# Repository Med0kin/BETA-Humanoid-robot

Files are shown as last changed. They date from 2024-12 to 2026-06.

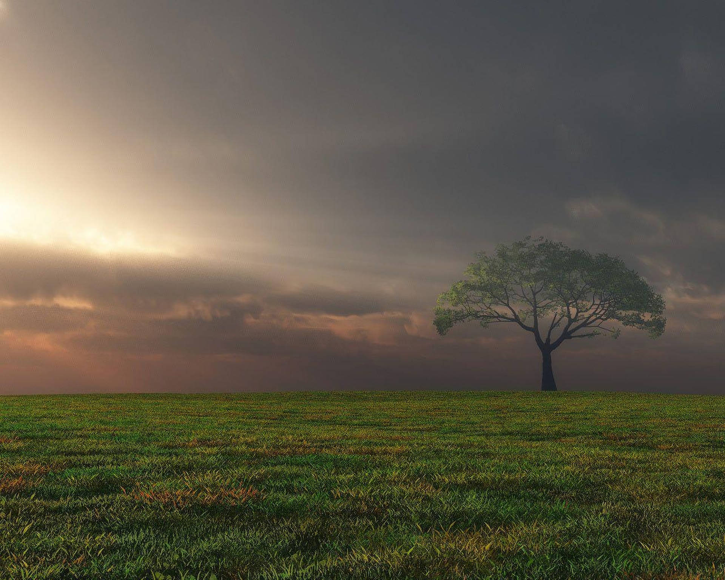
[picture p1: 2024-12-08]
gui/view/resources/background.png

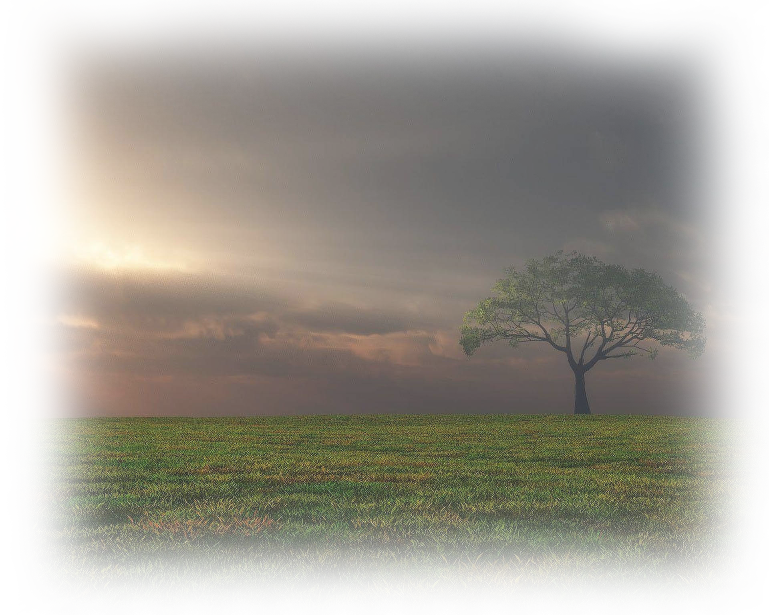
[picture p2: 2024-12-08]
gui/view/resources/background_01.png

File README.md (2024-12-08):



## Table of content

- [Humanoid robot *BETA*](#humanoid-robot-beta)
- [Built with](#built-with)
  - [Hardware components](#hardware-components)
  - [Programming language](#programming-language)
  - [Used libraries](#used-libraries)
- [Construction](#construction)
- [Power supply](#power-supply)
- [Servo control](#servo-control)
  - [Disclaimer](#disclaimer)
  - [Pulse Servo](#pulse-servo)
  - [Bus Servo](#bus-servo)
  - [Sequencial movement](#sequencial-movement)
- [Application](#application)
- [Speech-to-text](#speech-to-text)
- [Pose estimation](#pose-estimation)
- [Safety precautions](#safety-precautions)
- [Future plans](#future-plans)

## Humanoid robot *BETA*

BETA is an ambitious undertaking that seeks to develop a humanoid robot possessing a range of human-like capabilities, including the ability to walk, see, and communicate verbally.

Conceived in 2018, the project has undergone several transformations and upgrades over the years. Currently, it is being developed as part of the *"Koło Naukowe Humanoid"* student research circle. Updates on its progress and new features are regularly shared on the group's [Facebook page](https://www.facebook.com/KNHStyleOfficial).

<p align="center">
  
</p>

## Built with

### Hardware components

- [Raspberry Pi 4 Model B](https://www.raspberrypi.com/products/raspberry-pi-4-model-b/)
- [Raspberry Pi display](https://www.dfrobot.com/product-1784.html)
- [Bus servos](https://en.ocservo.com/?post_type=products&page_id=16170)
- Pulse servos: [RDS3235-180](https://pl.aliexpress.com/item/32734965011.html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) and [RDS3115-270](https://pl.aliexpress.com/item/32270225462.html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)
- USB Webcam

### Programming language

The programming language of choice for the project is Python. This decision was made because of its ease of use, large community, large number of libraries and frameworks and cross-platform compatilibity. Additionally, Python is a versatile language that can be used to develop a wide range of applications, including those that are used for the control of the robot's servos, the implementation of its vision system, and the development of its speech recognition capabilities.

### Used libraries

- [PySide2](https://pypi.org/project/PySide2/) - GUI toolkit used in [Application](#application)
- [Selenium](https://www.selenium.dev/) - automation of browser used in [Speech-to-text](#speech-to-text)
- [OpenCV](https://opencv.org/) - real-time computer vision used in [Pose estimation](#pose-estimation)
- [OCServo](https://github.com/Shinnken/OCServo_App/) - servo control app used in [Servo control](#servo-control)
- [pigpio](https://pypi.org/project/pigpio/) - control of GPIO to generate software PWM signal to control [Pulse servos](#disclaimer).

## Construction

The framework of the robot is composed of a hybrid of components that are either 3D-printed, purchased, or self-fabricated. The design of these parts was created in Blender, a 3D modeling software, and subsequently constructed by our team.

<p align="center">
  
</p>

Additionally, a 3D printer was utilized to produce the robot's chest component.

## Power supply

Humanoid robot BETA is powered by a combination of two step-up voltage regulators that convert 5V to 6V and 5V to 12V respectively. While this power supply configuration is functional, it is not an ideal solution for providing power to the robot's components.

## Servo control

As previously stated, our project utilizes two distinct types of servos. Due to their differing control mechanisms, we have partitioned their descriptions into two distinct subcategories.

### Disclaimer

Our use of the term "pulse" refers to a conventional servo that employs a Pulse Width Modulation (PWM) signal as its control input.

### Pulse Servo

Using mentioned library we've created tool to control servos with single commands.
To affix the servos to the robot's framework, we employ brackets that are included in the kit alongside the servos. The Raspberry Pi's GPIO pins serve as the source of the PWM signal, which is generated by utilizing the software [pigpio library](https://pypi.org/project/pigpio/). We have developed a tool utilizing the aforementioned library, which allows for the control of the servos through the use of single commands.

<p align="center">
  
</p>

During the process of developing the robot, it became apparent that the existing servos were not ideally suited to our requirements, as they were prone to excessive play and struggled to maintain a fixed position. As a result, we made the decision to incorporate [Bus servos](#bus-servo) in the leg joints, as these offer superior stability and control. By leveraging this approach, we can enhance the overall performance and reliability of the system, while enabling greater precision and accuracy in its movements.

### Bus Servo

In regards to the management of the second group of servos, communication is established through the utilization of the UART protocol, as the servos in question incorporate internal electronics. This approach enables efficient transmission of commands and data, as well as simplifying the wiring and control of the servos. By interfacing with the internal electronics of the servos, the system can achieve greater precision and flexibility in its movements.

<p align="center">
  
</p>

For more information about Bus servo control check out our [Servo library](https://github.com/Shinnken/OCServo_App/).

### Sequencial movement

To achieve smooth movement of our robot, we have developed a tool that enables the sequential control of servos. The primary objective of this tool is to facilitate the coordinated movement of servos to achieve seamless motion.

The program operates by utilizing text files, which contain data regarding the angles of each servo required for a given pose. By compiling a list of various poses, complex movements can be achieved through the sequential execution of poses. To create these text files, we have developed a custom tool that allows for the adjustment of the robot to a desired pose and the subsequent saving of this pose to a text file for later use.

<p align="center">
  
  
</p>

## Application

The software application that has been developed utilizes the PySide2 library to create a graphical user interface (GUI). The primary objective of this application is to enable the user to manage and manipulate the behavior of a robot through a touch screen interface.

<p align="center">
  
  
</p>

## Speech-to-text

For the purpose of speech-to-text, we have utilized the speech to textV website. The website is accessed through the use of the Selenium library. The library allows for the automation of the browser, which enables the implementation of the speech-to-text functionality.

One possible solution to address this issue is to utilize an application programming interface (API) that provides speech-to-text functionality. However, after careful consideration, it was determined that this approach was not optimal due to cost implications and implementation complexity. As an alternative, a solution was chosen that is both cost-effective and easy to implement, and does not impose excessive demands on computer resources.

## Pose estimation

For the purpose of pose estimation, the project team has chosen to use ArUco trackers, which are part of the OpenCV library. This is because ArUco markers are an efficient and accurate type of fiducial marker that can be easily detected and identified in image or video streams. By attaching multiple ArUco markers to the human's limbs and joints, the position and orientation of these markers can be tracked to estimate the robot's pose with a high degree of accuracy.

<p align="center">
  
</p>

In order to collect information about the location and orientation of the human body's joints and calculate angles for the robot, ArUco trackers will be attached to the human body. At this time, no other solutions have been selected for pose estimation purposes.

## Safety precautions

While operating humanoid robot BETA, it is important to take the necessary safety precautions to prevent injury or damage to the robot or its surroundings. Please read the following guidelines carefully before using the robot:

- Supervision: Always supervise the robot when it is in use. Do not leave the robot unattended around small children or pets.

- Operating environment: Use the robot in a safe and controlled environment. Avoid using the robot near stairs, ledges, or other hazards that could cause the robot to fall or be damaged.

- Power source: Only use the power source specified in the documentation. Do not use unauthorized power sources or chargers, as this could damage the robot or cause a fire.

- Servo control: When controlling the robot's servos, be aware of their range of motion and potential speed. Do not exceed the recommended range or speed, as this could damage the robot or cause it to malfunction.

- Maintenance: Regularly inspect the robot for wear and tear such as loose screws, frayed wires, or damaged components. If any issues are found, take the necessary steps to repair or replace the affected parts.

- Transport: When transporting the robot, make sure it is securely fastened and protected from damage.

By following these safety precautions, you can help ensure the safe and reliable operation of your humanoid robot BETA.

## Future plans

- [Power supply](#power-supply)

We plan to upgrade the power supply to a more efficient and stable configuration that uses step-down voltage regulators to convert 12V to 5V and 12V to 6V respectively.

The proposed power supply solution involves the use of a 3-cell lithium-ion battery.

By using a step-down voltage regulator to convert the 12V output from the battery to 5V and 6V respectively, we can ensure a stable and efficient power supply for the robot's components. This power supply solution also provides the added benefit of making the robot battery-powered, which increases its mobility and versatility.

We are confident that this proposed power supply solution will provide a safe, efficient, and reliable source of power for Humanoid robot BETA, and we look forward to implementing this upgrade in the near future.

- [Servo control](#servo-control)

As part of our future development plans, we intend to upgrade the current servos with more powerful alternatives. This enhancement will enable the creation of more intricate and sophisticated movements. In addition, we plan to incorporate a more advanced control system, which will allow for the implementation of more complex behaviors and actions.

- [Pose estimation](#pose-estimation)

The project team is considering adding gyroscope sensors to provide a more accurate source of information for angle estimation, thus allowing the robot to replicate human movements more accurately. Furthermore, a combination of different solutions, such as ArUco trackers, 2D pose estimation, and gyroscopes, may be tested to determine which approach yields the best results.

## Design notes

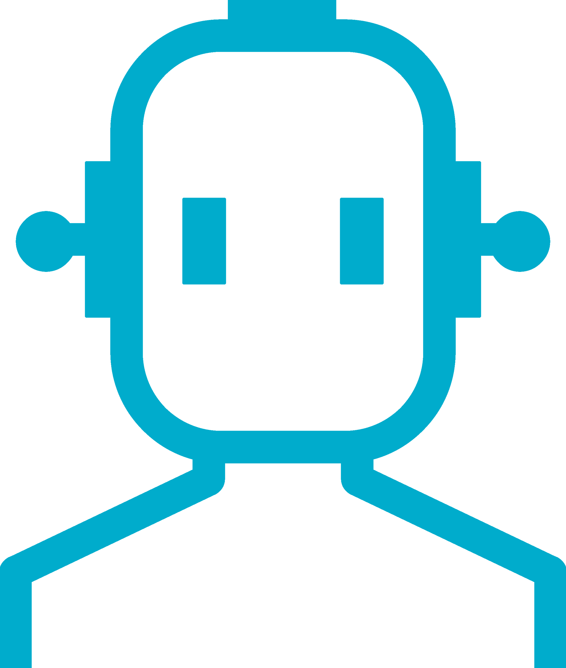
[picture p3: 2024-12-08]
gui/view/resources/full_face.png

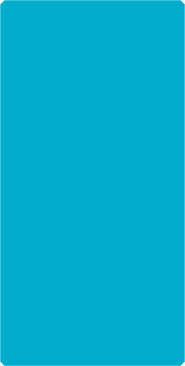
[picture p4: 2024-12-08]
gui/view/resources/eye.png

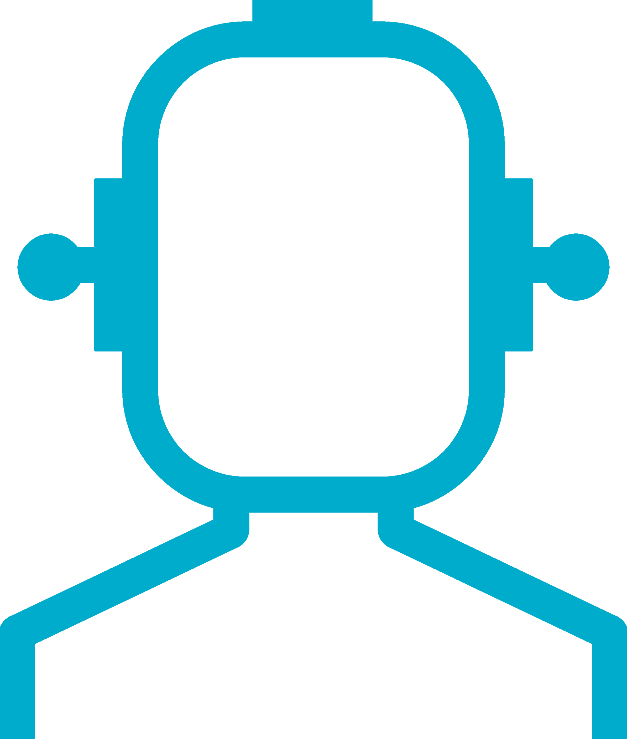
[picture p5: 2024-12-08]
gui/view/resources/face.png

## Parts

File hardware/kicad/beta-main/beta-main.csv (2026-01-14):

'Reference' | 'Value' | 'Footprint' | 'Datasheet' | 'Qty' | 'DigiKey_Part_Number' | 'MANUFACTURER' | 'MP' | 'Supplier' | 'DNP' | 'Exclude from BOM' | 'Exclude from Board'
'C1,C22,C23' | '0.1u' | 'Capacitor_SMD:C_0603_1608Metric' | '~' | '3' | '2571-GMC10X7R104K50NTTR-ND' | 'Cal-Chip Electronics, Inc.' | 'GMC10X7R104K50NT' | '' | '' | '' | ''
'C2' | '220u' | 'Capacitor_THT:CP_Radial_D8.0mm_P3.50mm' | '~' | '1' | '493-15344-ND' | 'Nichicon' | 'UKL1A221KPDANA' | '' | '' | '' | ''
'C3,C4,C5,C6,C7,C8,C9,C13,C15,C16,C18,C20,C21' | '10u' | 'Capacitor_SMD:C_0603_1608Metric' | 'https://search.murata.co.jp/Ceramy/image/img/A01X/G101/ENG/GRM21BR71A106KA73-01.pdf,~' | '13' | '478-KGM15CS61C106KTDKR-ND' | 'KYOCERA AVX' | '0603YW106KAT2A' | '' | '' | '' | ''
'C10' | '4.7nF' | 'Capacitor_SMD:C_0603_1608Metric' | '~' | '1' | '445-9141-2-ND' | 'TDK Corporation' | 'CGJ3E2X7R2A472K080AA' | '' | '' | '' | ''
'C11,C14,C17,C19' | '22u' | 'Capacitor_SMD:C_0603_1608Metric' | '~' | '4' | '478-KAM15CT70G226KTDKR-ND' | 'KYOCERA AVX' | 'KAM15CT70G226KT' | '' | '' | '' | ''
'C12' | '100u' | 'Capacitor_SMD:CP_Elec_6.3x7.7' | '~' | '1' | '565-EMHJ160ARA101MF80GTR-ND' | 'Chemi-Con' | 'EMHJ160ARA101MF80G' | '' | '' | '' | ''
'CM5' | 'ComputeModule5-CM5' | 'CM5IO:Raspberry-Pi-5-Compute-Module' | '' | '1' | '' | '' | '' | '' | '' | '' | ''
'D1' | 'LED_RED' | 'LED_SMD:LED_0603_1608Metric' | '~' | '1' | '5962-XL-1608VRC-06TR-ND' | 'XINGLIGHT' | 'XL-1608VRC-06' | '' | '' | '' | ''
'D2' | '1N5819WS' | 'Diode_SMD:D_SOD-323' | '~' | '1' | '5399-1N5819WSDKR-ND' | 'Shenzhen Slkormicro Semicon Co., Ltd.' | '1N5819WS' | '' | '' | '' | ''
'J1' | 'AUDIO' | 'Connector_JST:JST_PH_B2B-PH-K_1x02_P2.00mm_Vertical' | '~' | '1' | '455-B2B-PH-KL-ND' | 'JST Sales America Inc.' | 'B2B-PH-KL' | '' | '' | '' | ''
'J2' | 'USB3-0' | 'Connector_JST:JST_PH_B8B-PH-K_1x08_P2.00mm_Vertical' | '~' | '1' | '' | '' | '' | '' | '' | '' | ''
'J3' | 'USB3-1' | 'Connector_JST:JST_PH_B8B-PH-K_1x08_P2.00mm_Vertical' | '~' | '1' | '' | '' | '' | '' | '' | '' | ''
'J5' | 'DSI' | 'Connector_FFC-FPC:TE_1-84953-5_1x15-1MP_P1.0mm_Horizontal' | '~' | '1' | 'A101405DKR-ND' | 'TE Connectivity AMP Connectors' | '1-84953-5' | 'https://www.tme.eu/pl/details/ffc3a20-15-g/zlacza-ffc-fpc-raster-1-00mm/gct/' | '' | '' | ''
'J8' | 'CSI' | 'Connector_FFC-FPC:TE_1-84953-5_1x15-1MP_P1.0mm_Horizontal' | '~' | '1' | '' | '' | '' | 'https://www.tme.eu/pl/details/ffc3a20-15-g/zlacza-ffc-fpc-raster-1-00mm/gct/' | '' | '' | ''
'J10,J11,J12,J13' | 'Servo Socket' | 'Connector_JST:JST_XH_S3B-XH-A_1x03_P2.50mm_Horizontal' | '~' | '4' | '455-S3B-XH-A-ND' | 'JST Sales America Inc.' | 'S3B-XH-A' | '' | '' | '' | ''
'J14,J15,J16,J17' | 'Conn_01x04_Pin' | 'Connector_JST:JST_PH_S4B-PH-K_1x04_P2.00mm_Horizontal' | '~' | '4' | '' | '' | '' | '' | '' | '' | ''
'J18' | 'XT60' | 'Connector_AMASS:AMASS_XT60-F_1x02_P7.20mm_Vertical' | '~' | '1' | '' | '' | '' | '' | '' | '' | ''
'J19' | 'FAN0' | 'Connector_JST:JST_PH_B2B-PH-K_1x02_P2.00mm_Vertical' | '~' | '1' | '455-B2B-PH-KL-ND' | 'JST Sales America Inc.' | 'B2B-PH-KL' | '' | '' | '' | ''
'J20,J24,J25' | 'FAN1' | 'Connector_JST:JST_PH_B2B-PH-K_1x02_P2.00mm_Vertical' | '~' | '3' | '455-B2B-PH-KL-ND' | 'JST Sales America Inc.' | 'B2B-PH-KL' | '' | '' | '' | ''
'J21' | 'PWR' | 'Connector_JST:JST_PH_B2B-PH-K_1x02_P2.00mm_Vertical' | '~' | '1' | '455-B2B-PH-KL-ND' | 'JST Sales America Inc.' | 'B2B-PH-KL' | '' | '' | '' | ''
'J22' | 'AUDIO_IN0' | 'Connector_JST:JST_PH_B6B-PH-K_1x06_P2.00mm_Vertical' | '~' | '1' | '' | '' | '' | '' | '' | '' | ''
'J23' | 'AUDIO_IN1' | 'Connector_JST:JST_PH_B6B-PH-K_1x06_P2.00mm_Vertical' | '~' | '1' | '' | '' | '' | '' | '' | '' | ''
'L1,L2' | '2.2u' | 'CM5IO:L_Bourns_SRP5030CC' | 'https://www.bourns.com/docs/product-datasheets/srp5030cc.pdf,~' | '2' | '118-SRP5030CC-2R2MDKR-ND' | 'Bourns Inc.' | 'SRP5030CC-2R2M' | '' | '' | '' | ''
'Q1' | 'MMBT3906' | 'Package_TO_SOT_SMD:SOT-23' | 'https://www.onsemi.com/pdf/datasheet/pzt3906-d.pdf' | '1' | '3372-MMBT3906TR-ND' | 'MDD' | 'MMBT3906' | 'https://www.tme.eu/en/details/mmbt3906-tp/pnp-smd-transistors/micro-commercial-components/' | '' | '' | ''
'Q2' | 'IRLML6246TRP' | 'Package_TO_SOT_SMD:SOT-23' | '~' | '1' | 'IRLML6246TRPBFDKR-ND' | 'Infineon Technologies' | 'IRLML6246TRPBF' | '' | '' | '' | ''
'R1' | '20k' | 'Resistor_SMD:R_0603_1608Metric' | '~' | '1' | 'CR0603-JW-203ELFCT-ND' | 'Bourns Inc.' | 'CR0603-JW-203ELF' | '' | '' | '' | ''
'R2,R3,R4,R5,R13,R14,R16' | '10k' | 'Resistor_SMD:R_0603_1608Metric' | '~' | '7' | '311-10KGRCT-ND' | 'YAGEO' | 'RC0603JR-0710KL' | '' | '' | '' | ''
'R6' | '100K 1%' | 'Resistor_SMD:R_0603_1608Metric' | 'https://fscdn.rohm.com/en/products/databook/datasheet/passive/resistor/chip_resistor/mcr-e.pdf' | '1' | '311-100KHRCT-ND' | 'YAGEO' | 'RC0603FR-07100KL' | '' | '' | '' | ''
'R7' | '220K' | 'Resistor_SMD:R_0603_1608Metric' | '~' | '1' | '2019-RK73B1JTTD224JTR-ND' | 'KOA Speer Electronics, Inc.' | 'RK73B1JTTD224J' | '' | '' | '' | ''
'R8' | '30K' | 'Resistor_SMD:R_0603_1608Metric' | '~' | '1' | '311-30KGRTR-ND' | 'YAGEO' | 'RC0603JR-0730KL' | '' | '' | '' | ''
'R9' | '15k' | 'Resistor_SMD:R_0603_1608Metric' | 'https://fscdn.rohm.com/en/products/databook/datasheet/passive/resistor/chip_resistor/mcr-e.pdf' | '1' | '311-15KGRTR-ND' | 'YAGEO' | 'RC0603JR-0715KL' | '' | '' | '' | ''
'R10' | '10K 1%' | 'Resistor_SMD:R_0603_1608Metric' | 'https://fscdn.rohm.com/en/products/databook/datasheet/passive/resistor/chip_resistor/mcr-e.pdf' | '1' | '311-10.0KHRDKR-ND' | 'YAGEO' | 'RC0603FR-0710KL' | '' | '' | '' | ''
'R11' | '2.2K 1%' | 'Resistor_SMD:R_0603_1608Metric' | 'https://fscdn.rohm.com/en/products/databook/datasheet/passive/resistor/chip_resistor/mcr-e.pdf' | '1' | '311-2.20KHRCT-ND' | 'YAGEO' | 'RC0603FR-072K2L' | '' | '' | '' | ''
'R12' | '1k' | 'Resistor_SMD:R_0603_1608Metric' | '~' | '1' | '2019-RK73B1JTTD102JTR-ND' | 'KOA Speer Electronics, Inc.' | 'RK73B1JTTD102J' | '' | '' | '' | ''
'R15' | '2.2k' | 'Resistor_SMD:R_0603_1608Metric' | '~' | '1' | '' | '' | '' | '' | '' | '' | ''
'TP1' | '5V' | 'TestPoint:TestPoint_Pad_D1.0mm' | '~' | '1' | '' | '' | '' | '' | '' | '' | ''
'TP2' | '3V3' | 'TestPoint:TestPoint_Pad_D1.0mm' | '~' | '1' | '' | '' | '' | '' | '' | '' | ''
'U1' | 'MAX98357A' | 'Package_DFN_QFN:TQFN-16-1EP_3x3mm_P0.5mm_EP1.23x1.23mm' | 'https://www.analog.com/media/en/technical-documentation/data-sheets/MAX98357A-MAX98357B.pdf' | '1' | 'MAX98357AETE+TDKR-ND' | 'Analog Devices Inc./Maxim Integrated' | 'MAX98357AETE+T' | '' | '' | '' | ''
'U2,U4' | '74LVC1G126' | 'Package_TO_SOT_SMD:SOT-23-5' | '' | '2' | '5272-SN74LVC1G126DBVR-EVDKR-ND' | 'EVVO' | 'SN74LVC1G126DBVR-EV' | 'https://www.tme.eu/en/details/sn74lvc1g126dbvr/buffers-transceivers-drivers/texas-instruments/' | '' | '' | ''
'U3' | 'BNO086' | 'BETA:IC_BNO086' | '' | '1' | '1888-BNO086CT-ND' | 'Hillcrest Laboratories, Inc.' | 'BNO086' | '' | '' | '' | ''
'U5' | 'AP3441SHE-7B' | 'Package_DFN_QFN:DFN-8-1EP_2x2mm_P0.5mm_EP1.05x1.75mm' | 'https://www.diodes.com/assets/Datasheets/AP3441-L.pdf' | '1' | 'AP3441SHE-7BDIDKR-ND' | 'Diodes Incorporated' | 'AP3441SHE-7B' | '' | '' | '' | ''
'U6' | 'TPS56624x' | 'Package_TO_SOT_SMD:SOT-563' | 'https://www.ti.com/lit/ds/symlink/tps566242.pdf' | '1' | '' | '' | '' | '' | '' | '' | ''
'U7' | 'AP2553W6' | 'Package_TO_SOT_SMD:SOT-23-6' | 'https://www.diodes.com/assets/Datasheets/AP255x.pdf' | '1' | 'AP2553W6-7DIDKR-ND' | 'Diodes Incorporated' | 'AP2553W6-7' | '' | '' | '' | ''
'FID1,FID2,FID3' | '~' | 'Fiducial:Fiducial_1mm_Mask2mm' | '~' | '3' | '' | '' | '' | '' | '' | 'Excluded from BOM' | ''
'J4,J7' | 'USB3-1' | 'Connector_JST:JST_PH_S8B-PH-K_1x08_P2.00mm_Horizontal' | '~' | '2' | '' | '' | '' | '' | '' | 'Excluded from BOM' | 'Excluded from board'
'J6,J9' | 'USB3_A' | 'BETA:22009L012N1' | '~' | '2' | '' | '' | '' | '' | '' | 'Excluded from BOM' | 'Excluded from board'
'JP1' | 'SolderJumper_2_Open' | 'BETA:SolderJumper-2' | '~' | '1' | '' | '' | '' | '' | '' | 'Excluded from BOM' | ''
'MH1,MH3,MH5,MH7' | 'M3' | 'MountingHole:MountingHole_3.2mm_M3_Pad_Via' | '~' | '4' | '' | '' | '' | '' | '' | 'Excluded from BOM' | ''
'MH9,MH10,MH11,MH12' | 'M2.5' | 'MountingHole:MountingHole_2.7mm_Pad' | '~' | '4' | '' | '' | '' | '' | '' | 'Excluded from BOM' | ''

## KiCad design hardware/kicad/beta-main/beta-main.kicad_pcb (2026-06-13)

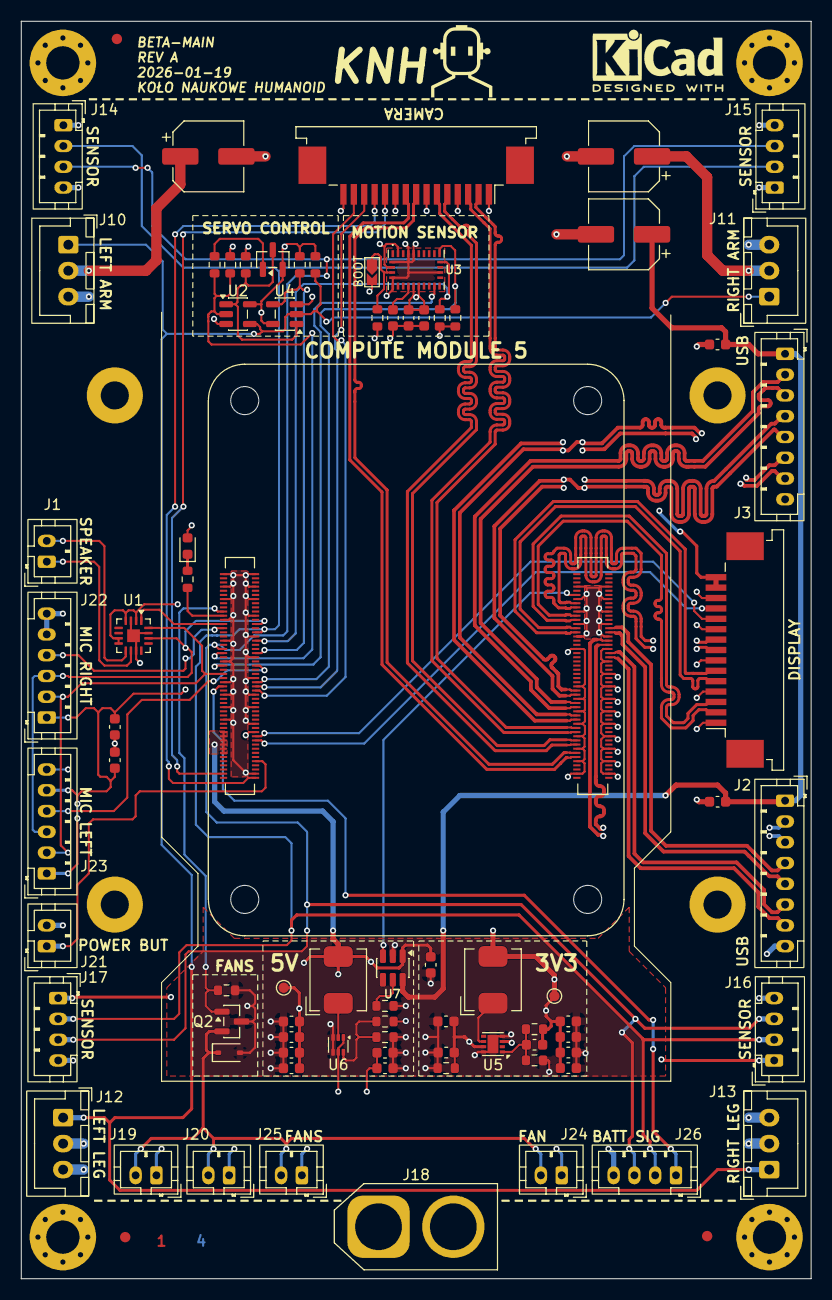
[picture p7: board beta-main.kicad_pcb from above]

Board: 4 copper layers, 76.0 x 121.0 mm, 90 parts (0 on the bottom side), 66 nets.

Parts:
C1, C22, C23: 0.1u; C_0603_1608Metric
C2, C12, C24: 100u; CP_Elec_6.3x5.7
C3, C4, C5, C6, C7, C8, C9, C11, C13, C14, C15, C16, C17, C18, C19, C20, C21: 10u; C_0603_1608Metric
C10: 4.7nF; C_0603_1608Metric
CM5: ComputeModule5-CM5; Raspberry-Pi-5-Compute-Module
D1: LED_RED; LED_0603_1608Metric
D2: 1N5819WS; D_SOD-323
FID1, FID2, FID3: Fiducial_1mm_Mask2mm
J1, J19, J20, J21, J24, J25: Conn_01x02_Pin; JST_PH_B2B-PH-K_1x02_P2.00mm_Vertical
J2, J3: Conn_01x08_Pin; JST_PH_B8B-PH-K_1x08_P2.00mm_Vertical
J5, J8: FFC; TE_1-84953-5_1x15-1MP_P1.0mm_Horizontal
J10, J11, J12, J13: Conn_01x03_Pin; JST_XH_B3B-XH-A_1x03_P2.50mm_Vertical
J14, J15, J16, J17, J26: Conn_01x04_Pin; JST_PH_B4B-PH-K_1x04_P2.00mm_Vertical
J18: XT60; AMASS_XT60-F_1x02_P7.20mm_Vertical
J22, J23: Conn_01x06_Pin; JST_PH_B6B-PH-K_1x06_P2.00mm_Vertical
JP1: SolderJumper_2_Open; SolderJumper-2
L1, L2: 2.2u; L_Bourns_SRP5030CC
MH1, MH3, MH5, MH7: M3; MountingHole_3.2mm_M3_Pad_Via
MH9, MH10, MH11, MH12: M2.5; MountingHole_2.7mm_Pad
Q1: MMBT3906; SOT-23
Q2: IRLML6246TRP; SOT-23
R1: 20k; R_0603_1608Metric
R2, R3, R4, R5, R6, R13, R14, R15, R16: 10k; R_0603_1608Metric
R7: 220K; R_0603_1608Metric
R8: 30K; R_0603_1608Metric
R9: 15k; R_0603_1608Metric
R10: 10K 1%; R_0603_1608Metric
R11: 2.2K 1%; R_0603_1608Metric
R12: 100; R_0603_1608Metric
TP1: 5V; TestPoint_Pad_D1.0mm
TP2: 3V3; TestPoint_Pad_D1.0mm
U1: MAX98357A; TQFN-16-1EP_3x3mm_P0.5mm_EP1.23x1.23mm
U2, U4: 74LVC1G126; SOT-23-5
U3: BNO086; IC_BNO086
U5: AP3441SHE-7B; DFN-8-1EP_2x2mm_P0.5mm_EP1.05x1.75mm
U6: TPS56624x; SOT-563
U7: AP2553W6; SOT-23-6

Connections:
+3V3: C7.1, C8.1, C10.1, C13.1, C16.1, C18.1, C20.1, C22.1, C23.1, CM5.78 (GPIO_VREF(1.8v/3.3v_Input)), D1.2 (A), J5.14, J5.15, J8.15, J14.1, J15.1, J16.1, J17.1, J22.1, J23.1, J23.5, L2.2, Q1.2 (E), R3.1, R4.1, R5.1, R10.1, R14.1, R15.1, R16.1, TP2.1, U1.2 (GAIN_SLOT), U1.4 (~SD_MODE), U1.7 (VDD), U1.8 (VDD), U2.5 (VCC), U3.3 (VDD), U3.10 (CLKSEL0), U3.11 (~RST), U3.28 (VDDIO), U4.5 (VCC)
+5V: C4.1, C5.1, C9.1, C11.1, C14.1, C17.1, C19.1, CM5.77 (+5v_(Input)), CM5.79 (+5v_(Input)), CM5.81 (+5v_(Input)), CM5.83 (+5v_(Input)), CM5.85 (+5v_(Input)), CM5.87 (+5v_(Input)), L1.2, R6.1, R7.1, TP1.1, U5.3 (VIN), U5.7 (EN), U7.1 (IN)
+BATT: C2.1, C3.1, C6.1, C24.1, J10.2, J11.2, J12.2, J13.2, J18.2, J19.1, J20.1, J24.1, J25.1, U6.1 (VIN), U6.5 (EN)
/CAM_GPIO0: CM5.97 (CAM_GPIO0), J8.11
/CAM_GPIO1: CM5.100 (CAM_GPIO1), J8.12
/GPIO/BATT_INT: CM5.55 (GPIO14), J26.1
/GPIO/FAN_PWM: CM5.19 (FAN_PWM), Q2.1 (G), R13.1
/GPIO/I2C2_SCL: CM5.34 (GPIO5), R15.2, U3.19 (H_SCL/SCK/RX)
/GPIO/I2C2_SDA: CM5.54 (GPIO4), R16.2, U3.20 (H_SDA/H_MISO/TX)
/GPIO/PWR_BUT: CM5.92 (PWR_BUT), J21.1
/GPIO/SDI: CM5.45 (GPIO24), U3.14 (~H_INT)
/GPIO/UART3_RX: CM5.40 (GPIO9), R5.2, U4.4
/GPIO/UART3_TX: CM5.39 (GPIO8), R2.2, R3.2, U2.2
/High Speed Serial/USB3-0-D_N: CM5.136 (USB3-0-D_N), J2.2
/High Speed Serial/USB3-0-D_P: CM5.134 (USB3-0-D_P), J2.3
/High Speed Serial/USB3-0-RX_N: CM5.128 (USB3-0-RX_N), J2.4
/High Speed Serial/USB3-0-RX_P: CM5.130 (USB3-0-RX_P), J2.5
/High Speed Serial/USB3-0-TX_N: CM5.140 (USB3-0-TX_N), J2.6
/High Speed Serial/USB3-0-TX_P: CM5.142 (USB3-0-TX_P), J2.7
/High Speed Serial/USB3-1-D_N: CM5.165 (USB3-1-D_N), J3.2
/High Speed Serial/USB3-1-D_P: CM5.163 (USB3-1-D_P), J3.3
/High Speed Serial/USB3-1-RX_N: CM5.157 (USB3-1-RX_N), J3.4
/High Speed Serial/USB3-1-RX_P: CM5.159 (USB3-1-RX_P), J3.5
/High Speed Serial/USB3-1-TX_N: CM5.169 (USB3-1-TX_N), J3.6
/High Speed Serial/USB3-1-TX_P: CM5.171 (USB3-1-TX_P), J3.7
/I2S0_SCLK: CM5.49 (GPIO18), J22.2, J23.2, U1.16 (BCLK)
/I2S0_SDI0: CM5.27 (GPIO20), J22.4
/I2S0_SDI1: CM5.46 (GPIO22), J23.4
/I2S0_SDO: CM5.25 (GPIO21), U1.1 (DIN)
/I2S0_WS: CM5.26 (GPIO19), J22.3, J23.3, U1.14 (LRCLK)
/MIPI0_C_N: CM5.127 (MIPI0_C_N), J5.5
/MIPI0_C_P: CM5.129 (MIPI0_C_P), J5.6
/MIPI0_D0_N: CM5.115 (MIPI0_D0_N), J5.8
/MIPI0_D0_P: CM5.117 (MIPI0_D0_P), J5.9
/MIPI0_D1_N: CM5.121 (MIPI0_D1_N), J5.2
/MIPI0_D1_P: CM5.123 (MIPI0_D1_P), J5.3
/MIPI1_C_N: CM5.187 (MIPI1_C_N), J8.8
/MIPI1_C_P: CM5.189 (MIPI1_C_P), J8.9
/MIPI1_D0_N: CM5.175 (MIPI1_D0_N), J8.2
/MIPI1_D0_P: CM5.177 (MIPI1_D0_P), J8.3
/MIPI1_D1_N: CM5.181 (MIPI1_D1_N), J8.5
/MIPI1_D1_P: CM5.183 (MIPI1_D1_P), J8.6
/PSU/FB: C10.2, R10.2, R11.1, U5.1 (FB)
/Peripherals/SENSOR_SCL: CM5.37 (GPIO7), J14.3, J15.3, J16.3, J17.3, J26.3
/Peripherals/SENSOR_SDA: CM5.30 (GPIO6), J14.2, J15.2, J16.2, J17.2, J26.2
/Peripherals/SIG: J10.1, J11.1, J12.1, J13.1, R4.2, U2.4, U4.2
/Peripherals/TXEN: Q1.3 (C), R1.2, U2.1, U4.1
/SCL0: CM5.80 (SCL0), J5.11
/SCL1: CM5.56 (GPIO3), J8.13
/SDA0: CM5.82 (SDA0), J5.12
/SDA1: CM5.58 (GPIO2), J8.14
/VBUS_EN: CM5.111 (VBUS_EN), U7.3 (EN)
GND: C1.1, C2.2, C3.2, C4.2, C5.2, C6.2, C7.2, C8.2, C9.2, C11.2, C12.2, C13.2, C14.2, C15.2, C16.2, C17.2, C18.2, C19.2, C20.2, C21.2, C22.2, C23.2, C24.2, CM5.1 (GND), CM5.2 (GND), CM5.7 (GND), CM5.8 (GND), CM5.13 (GND), CM5.14 (GND), CM5.22 (GND), CM5.23 (GND), CM5.32 (GND), CM5.33 (GND), CM5.42 (GND), CM5.43 (GND), CM5.52 (GND), CM5.53 (GND), CM5.59 (GND), CM5.60 (GND), CM5.65 (GND), CM5.66 (GND), CM5.71 (GND), CM5.74 (GND), CM5.98 (GND), CM5.107 (GND), CM5.108 (GND), CM5.113 (GND), CM5.114 (GND), CM5.119 (GND), CM5.120 (GND), CM5.125 (GND), CM5.126 (GND), CM5.131 (GND), CM5.132 (GND), CM5.137 (GND), CM5.138 (GND), CM5.144 (GND), CM5.150 (GND), CM5.155 (GND), CM5.156 (GND), CM5.161 (GND), CM5.162 (GND), CM5.167 (GND), CM5.168 (GND), CM5.173 (GND), CM5.174 (GND), CM5.179 (GND), CM5.180 (GND), CM5.185 (GND), CM5.186 (GND), CM5.191 (GND), CM5.192 (GND), CM5.197 (GND), CM5.198 (GND), D2.2 (A), J2.8, J3.8, J5.1, J5.4, J5.7, J5.10, J5.13, J8.1, J8.4, J8.7, J8.10, J10.3, J11.3, J12.3, J13.3, J14.4, J15.4, J16.4, J17.4, J18.1, J21.2, J22.5, J22.6, J23.6, J26.4, JP1.2 (B), MH1.1, MH3.1, MH5.1, MH7.1, MH9.1, MH10.1, MH11.1, MH12.1, Q2.3 (S), R1.1, R6.2, R8.2, R9.2, R11.2, R13.2, U1.3 (GND), U1.11 (GND), U1.15 (GND), U1.17 (PAD), U2.3 (GND), U3.2 (GND), U3.5 (PS1), U3.6 (PS0/WAKE), U3.17 (SA0/H_MOSI), U3.25 (GNDIO), U3.26 (XOUT32/CLKSEL1), U4.3 (GND), U5.4 (PGND), U5.8 (SGND), U5.9 (PAD), U6.3 (GND), U6.4 (AGND), U7.2 (GND)
unnamed: CM5.21 (LED_nACT), R12.1
unnamed: D1.1 (K), R12.2
unnamed: D2.1 (K), J19.2, J20.2, J24.2, J25.2, Q2.2 (D)
unnamed: J1.1, U1.10 (OUTN)
unnamed: J1.2, U1.9 (OUTP)
unnamed: JP1.1 (A), R14.2, U3.4 (~BOOT)
unnamed: Q1.1 (B), R2.1
unnamed: C1.2, U3.9 (CAP)
unnamed: L2.1, U5.6 (LX)
unnamed: R7.2, R8.1, U6.6 (FB)
unnamed: L1.1, U6.2 (SW)
unnamed: R9.1, U7.5 (ILIM)
VBUS: C12.1, C15.1, C21.1, J2.1, J3.1, U7.6 (OUT)

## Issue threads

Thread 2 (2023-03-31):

:memo: rewritting windowApp comments

Med0kin, 2023-03-31:

Med0kin, 2023-10-18:
Extended Servo classes (PWMServo, BusServo) will be controlled using the same interface for easier control.

PWMServo class was tested successfully.

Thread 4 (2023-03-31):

🤖 3D model new chest

Med0kin, 2023-03-31:

Shinnken, 2023-04-02:
Should be done including [new PCB](https://github.com/Med0kin/BETA-Humanoid-robot/issues/5) project.

Closed 2025-07-05.

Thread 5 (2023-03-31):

🤖 Design new PCB that uses new PSU

Med0kin, 2023-03-31:

Shinnken, 2023-04-01:
To do:
- [ ] Pick and list all necessary components.
- [ ] Make PCB project that combines everything together
- [ ] Etching, drilling and filing prototype
- [ ] (Optional) Order professionaly made PCB

Med0kin, 2023-04-01:
## PSU and batteries
We're interested in switching from 5V to voltage in rage from 7V to 12V. As a result we've decided to use 11.1V battery created from [Li-ion batteries](https://botland.com.pl/akumulatory-li-ion/6463-ogniwo-18650-li-ion-samsung-inr18650-30q-3000mah-5904422350079.html), we need at least 6 of these.
When it comes to choosing PSU we want to consider following products:
[11V -> 5V ](https://www.pololu.com/product/4091)
[11V -> 6V](https://www.pololu.com/product/2882)
Also we need accessories:
[Brackets](https://botland.com.pl/koszyki-na-baterie/16519-koszyk-na-3-akumulatory-typu-18650-bez-przewodow-5904422378165.html)

Med0kin, 2023-04-01:
## Other onboard components
- We also need to buy [new pins](https://botland.com.pl/gniazda-szpilkowe-goldpin/6936-gniazdo-zenskie-2x20-raster-254mm-do-raspberry-pi-4b3b3b3b-dlugie-piny-12mm-5903351246125.html) for PCB that connects board with Raspberry Pi. We will be using the same that we used in previous PCB.
- [ARK connectors](https://botland.com.pl/zlacza-ark/810-zlacze-ark-kf301-raster-50mm-2-pin-10-szt-5904422329693.html)
- [Double-sided laminate](https://botland.com.pl/laminaty/1054-laminat-fr4-dwustronny-rozmiar-l-5903351248969.html), we might consider build few of these just in case.

Med0kin, 2023-04-01:
## What will be on the PCB...
### List of modules on the board
- 5V step-down voltage regulator
- 6V step-down voltage regulator
- "digital" servo driver
- set of pins that connects to raspberry and powers "analog" servos=

Med0kin, 2023-04-01:
### If you notice that something's missing feels free to edit comment.

Closed 2025-07-05.

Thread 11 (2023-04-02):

:robot: Design and create case for transporting robot

Med0kin, 2023-04-02:
## Proposition
The inside could me made with polyethylene foam sheet such as [this one](https://allegro.pl/oferta/pianka-polietylenowa-pe-60mm-1m-x-1-2m-czarna-6cm-7260400748?fromVariant=7260364292).
When it comes to case we could make use of something like [this](https://allegro.pl/oferta/walizka-aluminiowa-skrzynka-narzedziowa-narzedzia-9829628810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).

Closed 2025-07-05.

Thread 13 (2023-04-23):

✨ Design and create body tracking

Med0kin, 2023-04-23:

Med0kin, 2023-04-23:
Most likely, we will be using the GY-521 with the MPU-6050 module as it is a cost-effective option that supports the I2C interface, allowing for easy series connections.
[GY-521](https://allegro.pl/oferta/zyroskop-mpu-6050-gy-521-akcelerometr-3-osiowy-11726786431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)

Shinnken, 2023-05-07:
As we've discovered there is no simple way to change Mpu-6050's address, so we will be using 2D pose estimation combined with 2 gyroscopes, which hopefully will emirate 3D pose estimation.\

2D pose estimation that works with Coral Accelerator:
https://github.com/google-coral/project-posenet

Med0kin, 2023-10-18:
Hand tracking "wands" have approx. 1 meter distance when communicating with each other using radio communication which is not enough for our use case.

Closed 2025-07-05.

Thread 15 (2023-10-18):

:robot: Design PSU

Med0kin, 2023-10-18:
Design power supply using that includes:
- Battery
- Battery balancer
- 12V DC converter
- 5V DC converter

Closed 2025-07-05.

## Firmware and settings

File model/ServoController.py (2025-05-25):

import serial
from model import Servo, PWMServo, BusServo
from typing import Union, List, Tuple, Any
from array import array
from time import time

class ServoController:
    def __init__(self, servos: tuple = (), serial: serial.Serial = None) -> None:
        '''
        Constructor for ServoController class
        :param servos: Tuple of servos
        '''
        self._servos: tuple = servos
        self.serial = serial

    
    def move(self, servos: Union[list, tuple, array], positions: Union[list, tuple, array],
             times: Union[list, tuple, array, None] = None, verbose: bool = False) -> None:
        '''
        Moves the servos to the given positions in the given times (if given)
        :param servos: Servos to move (list, tuple or array)
        :param positions:
        '''
        DEFAULT_TIME = 1000
        if len(servos) != len(positions):
            raise ValueError("Servos and positions must be the same length")
        if times is not None and len(servos) != len(times):
            raise ValueError("Servos and times must be the same length")
        if times is None:
            times = [DEFAULT_TIME] * len(servos)

        int_type_check_list = [isinstance(servo, int) for servo in servos]
        servo_type_check_list = [isinstance(servo, Servo) for servo in servos]
        if all(int_type_check_list):
            servos = self._get_servos_by_ids(servos)
        elif all(servo_type_check_list):
            pass
        else:
            raise ValueError("Servos must be either all ints or all Servos")

        pwm_servos = tuple(servo for servo in servos if isinstance(servo, PWMServo))
        for servo in pwm_servos:
            servo.move(positions[servos.index(servo)], times[servos.index(servo)]/1000, verbose)
        
        bus_servos = tuple(servo for servo in servos if isinstance(servo, BusServo))
        bus_positions = [positions[servos.index(servo)] for servo in bus_servos]
        bus_times = [times[servos.index(servo)] for servo in bus_servos]
        self._move_multiple_bus(bus_servos, bus_positions, bus_times)
        if verbose:
            print(self._generate_move_info(servos, positions, times))
            
    def _generate_move_info(self, servos: Union[list, tuple, array], positions: Union[list, tuple, array], times: Union[list, tuple, array]) -> str:
        info = f"{time()} | Moving servos to positions:\n"
        for i in range(len(servos)):
            info += f"Servo {servos[i].id}: \t{servos[i].pos} -> {positions[i]} in {times[i]} ms\n"
        return info

    def _get_servos_by_ids(self, ids: Union[list, tuple, array]) -> list:
        servos = []
        for id in sorted(ids):
            for servo in self.servos:
                if servo.id == id:
                    servos.append(servo)
                    break
        if len(servos) != len(ids):
            raise ValueError("Not all IDs are valid")
        return servos
    
    def _move_multiple_bus(self, servos: Union[list, tuple, array], positions: Union[list, tuple, array], 
                           operation_time: Union[list, tuple, array]) -> None:
        data_length = 0
        INSTRUCTION = 0x83
        ADDRESS = 0x2a
        LENGTH = 0x04
        data = bytearray([0xff, 0xff, 0xfe, data_length, INSTRUCTION, ADDRESS, LENGTH])
        for i in range(len(servos)):
            if servos[i].is_inverted:
                positions[i] = 4095 - positions[i]          # Mirror the positions for left leg
            pos = positions[i].to_bytes(2, 'little')
            data.append(servos[i].id)
            data.append(pos[0])
            data.append(pos[1])
            spd = operation_time[i].to_bytes(2, 'little')
            data.append(spd[0])
            data.append(spd[1])
        data[3] = len(data) - 3
        data.append(self._checksum(data))
        self.serial.write(data)

    def _old_move_multiple_bus(self, servos: Union[list, tuple, array], positions: Union[list, tuple, array], 
                           operation_time: Union[list, tuple, array]) -> None:
    
        pass
        

    def _checksum(self, data: bytearray) -> int:
        '''
        Calculates the checksum of the data
        :param data: Data to calculate the checksum of
        :return: Checksum of the data
        '''
        checksum = 0
        for i in range(2, len(data)):
            checksum += data[i]
        if checksum > 255:
            checksum = checksum & 0xff
        return ~checksum & 0xff

    @property
    def servos(self) -> tuple:
        return self._servos

    @servos.setter
    def servos(self, servos: tuple) -> None:
        self._servos = servos

    def __len__(self) -> int:
        return len(self.servos)

    def __getitem__(self, index: int) -> Servo:
        return self.servos[index]

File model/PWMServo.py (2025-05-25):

import threading
from .Servo import Servo
import RPi.GPIO as GPIO
import pigpio as pg
from typing import Union
from time import sleep

class PWMServo(Servo):
    def __init__(self, id: int, max_pos: int,
                 min_pos: int, gpio_port: int,
                 servo_range: int = 180) -> None:
        '''
        Constructor for PWMServo class
        :param id: ID of the servo
        :param max_pos: Maximum pos of the servo
        :param min_pos: Minimum pos of the servo
        :param gpio_port: GPIO port of the servo
        :param servo_range: Range of the servo (default 180)
        '''
        super().__init__(id, max_pos, min_pos)
        self._MIN_SERVO_DUTY = 500
        self._MAX_SERVO_DUTY = 2500
        if max_pos > self._MAX_SERVO_DUTY or min_pos < self._MIN_SERVO_DUTY:
            raise ValueError("Position must be between 500 and 2500")
        self._servo_range = servo_range
        self._GPIO_PORT = gpio_port
        self._pigpio = self._setup_pigpiod(gpio_port)
        self._target_pos = 1500
        self._target_time = 0
        self._thread = threading.Thread(target=self._control_servo)
        self._thread_stop_event = threading.Event()
        self._thread.start()

    def move(self, pos: int, time: int = 0, verbose: bool = False) -> None:
        '''
        Moves the servo to the given position.
        :param pos: The target position to move the servo to.
        :param time: The time to reach the target position (default 0).
        :param verbose: Whether to print the position (default False).
        :raises RuntimeError: If the thread is not running.
        :raises ValueError: If the time is negative.
        :return: None
        '''
        if self.thread_stop_event.is_set():
            raise RuntimeError("Thread is not running, thread_stop_event is set")
        if time < 0:
            raise ValueError("Time cannot be negative")
        self.target_pos = pos
        self.target_time = time
        if verbose:
            print(self._generate_move_info(pos, time, verbose))

    def _setup_pigpiod(self, gpio_port: int) -> pg.pi:
        '''
        Sets up the pigpiod daemon
        :param gpio_port: GPIO port of the servo
        :return: pigpio object
        '''
        pigpio = pg.pi()
        pigpio.set_mode(gpio_port, pg.OUTPUT)
        pigpio.set_PWM_frequency(gpio_port, 50)
        pigpio.set_servo_pulsewidth(gpio_port, 1500)
        self.pos = 1500
        return pigpio

    def _control_servo(self) -> None:
        """
        Controls the servo to move to the target position
        (it is meant to be run in a thread)
        """
        current_goal = self.pos
        while not self._thread_stop_event.is_set():
            # Skip if already at target
            if self.target_pos == self.pos:
                sleep(0.01)  # Small sleep to prevent busy waiting
                continue
            
            # Handle immediate movement
            if self.target_time == 0:
                self.pigpio.set_servo_pulsewidth(self.GPIO_PORT, self.target_pos)
                self.pos = self.target_pos
                continue
            
            # Calculate movement parameters
            direction = 1 if self.target_pos > self.pos else -1
            travel = abs(self.target_pos - self.pos)
            step_size = max(1, min(5, travel // 10))  # Dynamic step size based on distance
            amount_of_steps = travel // step_size
            
            # Store current targets to detect changes
            current_target_pos = self.target_pos
            current_target_time = self.target_time
            
            # Calculate time per step
            time_per_step = current_target_time / amount_of_steps if amount_of_steps > 0 else 0
            
            # Movement loop
            for step in range(1, amount_of_steps + 1):
                if (self.target_pos != current_target_pos or 
                    self.target_time != current_target_time):
                    break  # Target changed, restart movement
                
                new_pos = self.pos + (step_size * direction)
                self.pigpio.set_servo_pulsewidth(self.GPIO_PORT, new_pos)
                self.pos = new_pos
                sleep(time_per_step)
            
            # Final position (in case we broke out early or had rounding errors)
            if self.target_pos == current_target_pos:  # Only if target didn't change
                self.pigpio.set_servo_pulsewidth(self.GPIO_PORT, current_target_pos)
                self.pos = current_target_pos

    @property
    def servo_range(self) -> int:
        return self._servo_range
    
    @property
    def GPIO_PORT(self) -> int:
        return self._GPIO_PORT

    @property
    def pigpio(self) -> pg.pi:
        return self._pigpio
    
    @property
    def target_pos(self) -> int:
        return self._target_pos

    @property
    def target_time(self) -> int:
        return self._target_time
    
    @property
    def thread(self) -> threading.Thread:
        return self._thread

    @property
    def thread_stop_event(self) -> threading.Event:
        return self._thread_stop_event

    @target_pos.setter
    def target_pos(self, pos: int) -> None:
        self._target_pos = pos

    @target_time.setter
    def target_time(self, time: int) -> None:
        self._target_time = time

    @thread.setter
    def thread(self, thread: threading.Thread) -> None:
        self._thread = thread

    def __str__(self) -> str:
        return super().__str__() + f"Servo range: {self._servo_range}\n"

    def __repr__(self) -> str:
        return (f"PWMServo({self.id}, {self.max_pos}, {self.min_pos}, "
                f"{self.servo_range})")

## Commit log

2025-01-06 Enhance GUI and model structure with new components and fixes
    - Added QAnimatedPixmapItem for animated graphics in the GUI.
    - Updated import paths for consistency across modules.
    - Improved Servo class with is_inverted property for better control.
    - Introduced Model class to manage servo instances and serial communication.
    - Fixed minor syntax issues and improved code readability.
    - Added initial test for BusServo functionality.
    [BusServo.py, PWMServo.py, Servo.py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]
2025-10-16 add kicad main board project
    [CM5.kicad_sch, beta-main.kicad_pcb, beta-main.kicad_sch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]
2025-10-16 tweaks and added servo controller
    [CM5.kicad_sch, beta-main.kicad_sch, gpio.kicad_sch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]
2025-10-17 add 5v power supply
    [psu.kicad_sch, psu_5v.kicad_sch]
2025-10-26 sync changes after meeting
    [CM5.kicad_sch, beta-main.kicad_sch, servo_controller.kicad_sch]
2025-10-29 Wzmacniacz dodany
    [CM5.kicad_sch, beta-main.kicad_sch, gpio.kicad_sch]
2025-11-02 Dodanie schematu sekcji zasilania 3V3
    [psu_3v3.kicad_sch]
2025-12-11 5V and amplifier corrections
    [CM5.kicad_sch, beta-main.kicad_sch, gpio.kicad_sch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]
2025-12-16 Amplifier set for left channel only and god rid of all errors from ERC
    [CM5.kicad_sch, beta-main.kicad_sch, gpio.kicad_sch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]
2025-12-18 Gyroscope added without errors in ERC
    [CM5.kicad_sch, beta-main.kicad_sch, gpio.kicad_sch]
2025-12-20 Setup for PCB layout
    [CM5.kicad_sch, beta-main.kicad_pcb, beta-main.kicad_sch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]
2025-12-22 remove power symbols from hierarchy and move different subsystems around
    [CM5.kicad_sch, beta-main.kicad_sch, gpio.kicad_sch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]
2025-12-22 use copied MAX98357 symbol to specify pin type
    [CM5.kicad_sch]
2025-12-23 BNO086 tweaked
    [sensors.kicad_sch]
2025-12-23 create template for components placement with drawn contraints
    [beta-main.kicad_pcb, servo_controller.kicad_sch]
2025-12-27 Rough layout with all elements, test point for 3V3 added. C footprints need to change to 6 3
    [beta-main.kicad_pcb, psu_3v3.kicad_sch]
2025-12-27 Datasheets added, camera and servo not included
2026-01-04 Footprints changed to 603
    [beta-main.kicad_pcb, psu_3v3.kicad_sch, psu_5v.kicad_sch]
2026-01-04 Footprints fixed, fuse removed
    [CM5.kicad_sch, beta-main.kicad_pcb, psu_5v.kicad_sch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]
2026-01-05 add modifications
    [CM5.kicad_sch, beta-main.kicad_pcb, beta-main.kicad_sch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]
2026-01-05 add filled zones and layout 5V and 3V3
    [beta-main.kicad_pcb, beta-main.kicad_sch, gpio.kicad_sch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]
2026-01-05 add fan control
    [beta-main.kicad_pcb, psu.kicad_sch]
2026-01-05 route servo controller
    [beta-main.kicad_pcb]
2026-01-09 route usb
    [beta-main.kicad_pcb]
2026-01-09 BOM passive
2026-01-10 BOM, all easily found parts from digi
    [beta-main.kicad_sch, gpio.kicad_sch, peripherals.kicad_sch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]
2026-01-12 resolve DRC issues and generate fab files
    [beta-main-B_Cu.gbr, beta-main-B_Mask.gbr, beta-main-B_Paste.gbr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]
2026-01-13 sync changes
    [beta-main.kicad_pcb, gpio.kicad_sch, peripherals.kicad_sch]
2026-01-19 add final touches, generate rev A fab and step files
    [beta-main-B_Cu.gbr, beta-main-B_Mask.gbr, beta-main-B_Paste.gbr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]
2026-01-20 regenerate fab files
    [beta-main-B_Cu.gbr, beta-main-B_Mask.gbr, beta-main-B_Paste.gbr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]
